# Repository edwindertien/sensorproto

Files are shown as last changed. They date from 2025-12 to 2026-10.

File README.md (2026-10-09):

# UniProto — sensor streaming for Arduino

UniProto is a tiny serial protocol, an Arduino library and a set of Python visualisers. Every
sensor or actuator in this repository — from a capacitive slider to a BLDC gimbal — speaks the
same few text commands, so a new setup is a short sketch plus a plotter, never a new protocol.
Built for the *Mastering Tinkering* and *Social Robot Design* courses at the University of Twente.

- **One protocol, many setups.** Enable a stream, set a rate, change a parameter: the same commands everywhere.
- **Firmware stays small.** A sketch registers *streams*, *parameters* and *actions*; the library does parsing, timing and formatting.
- **Readers are plain Python.** Each setup has a matplotlib (or browser) visualiser; anything that can read a serial port works too.
- **Any sketch is usable at once.** A generic web dashboard discovers a sketch's streams, parameters and actions by itself — [no plotter needed](#dashboard).

## Pick a setup

Click an icon to jump to its section.

<!-- GRID:START -->
<table>
<tr>
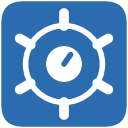
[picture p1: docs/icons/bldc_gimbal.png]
BLDC gimbal
<td align="center" valign="top" width="16%"><a href="#bldc-gimbal"><br><b>BLDC gimbal</b></a><br><sub>FOC haptic knob</sub></td>
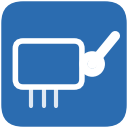
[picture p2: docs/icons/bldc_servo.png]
BLDC servo
<td align="center" valign="top" width="16%"><a href="#bldc-servo"><br><b>BLDC servo</b></a><br><sub>ESC, 50 Hz PWM</sub></td>
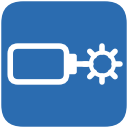
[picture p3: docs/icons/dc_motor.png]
DC motor
<td align="center" valign="top" width="16%"><a href="#dc-motor"><br><b>DC motor</b></a><br><sub>PID position / velocity</sub></td>
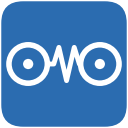
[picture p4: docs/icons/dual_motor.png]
Dual motor
<td align="center" valign="top" width="16%"><a href="#dual-motor"><br><b>Dual motor</b></a><br><sub>haptic master-slave</sub></td>
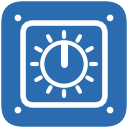
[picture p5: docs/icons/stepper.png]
Stepper
<td align="center" valign="top" width="16%"><a href="#stepper"><br><b>Stepper</b></a><br><sub>MKS SERVO42D</sub></td>
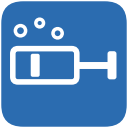
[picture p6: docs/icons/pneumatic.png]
Pneumatic
<td align="center" valign="top" width="16%"><a href="#pneumatic"><br><b>Pneumatic</b></a><br><sub>pump + pressure</sub></td>
</tr>
<tr>
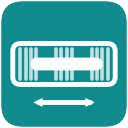
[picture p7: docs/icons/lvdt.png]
LVDT
<td align="center" valign="top" width="16%"><a href="#lvdt"><br><b>LVDT</b></a><br><sub>AC position sensor</sub></td>
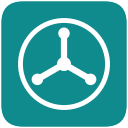
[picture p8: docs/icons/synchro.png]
Synchro
<td align="center" valign="top" width="16%"><a href="#synchro"><br><b>Synchro</b></a><br><sub>3-phase angle</sub></td>
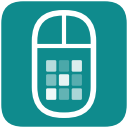
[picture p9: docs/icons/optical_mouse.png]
Optical mouse
<td align="center" valign="top" width="16%"><a href="#optical-mouse"><br><b>Optical mouse</b></a><br><sub>ADNS-2610 camera</sub></td>
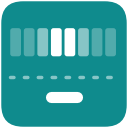
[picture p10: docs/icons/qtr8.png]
QTR-8
<td align="center" valign="top" width="16%"><a href="#qtr8"><br><b>QTR-8</b></a><br><sub>line / gray-code strip</sub></td>
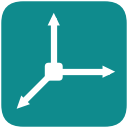
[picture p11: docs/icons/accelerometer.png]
Accelerometer
<td align="center" valign="top" width="16%"><a href="#accelerometer"><br><b>Accelerometer</b></a><br><sub>MMA7260, 3 axes</sub></td>
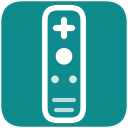
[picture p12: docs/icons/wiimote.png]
Wiimote IR
<td align="center" valign="top" width="16%"><a href="#wiimote"><br><b>Wiimote IR</b></a><br><sub>IR camera via I2C</sub></td>
</tr>
<tr>
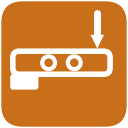
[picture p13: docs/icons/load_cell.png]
Load cell
<td align="center" valign="top" width="16%"><a href="#load-cell"><br><b>Load cell</b></a><br><sub>HX711 amplifier</sub></td>
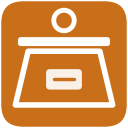
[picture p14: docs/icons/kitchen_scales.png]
Kitchen scales
<td align="center" valign="top" width="16%"><a href="#kitchen-scales"><br><b>Kitchen scales</b></a><br><sub>load cell + HX711</sub></td>
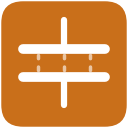
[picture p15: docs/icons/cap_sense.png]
Cap sense
<td align="center" valign="top" width="16%"><a href="#cap-sense"><br><b>Cap sense</b></a><br><sub>variable capacitor</sub></td>
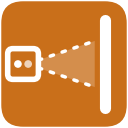
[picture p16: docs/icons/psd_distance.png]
IR distance
<td align="center" valign="top" width="16%"><a href="#psd-distance"><br><b>IR distance</b></a><br><sub>Sharp PSD</sub></td>
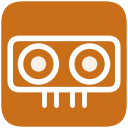
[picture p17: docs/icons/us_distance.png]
Ultrasonic
<td align="center" valign="top" width="16%"><a href="#us-distance"><br><b>Ultrasonic</b></a><br><sub>HC-SR04 scope view</sub></td>
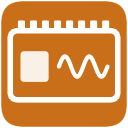
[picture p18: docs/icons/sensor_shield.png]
Sensor shield
<td align="center" valign="top" width="16%"><a href="#sensor-shield"><br><b>Sensor shield</b></a><br><sub>7 sensors, 1 board</sub></td>
</tr>
<tr>
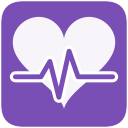
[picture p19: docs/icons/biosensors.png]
Biosensors
<td align="center" valign="top" width="16%"><a href="#biosensors"><br><b>Biosensors</b></a><br><sub>GSR + heart rate</sub></td>
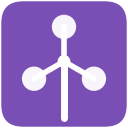
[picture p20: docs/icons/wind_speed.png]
Wind speed
<td align="center" valign="top" width="16%"><a href="#wind-speed"><br><b>Wind speed</b></a><br><sub>optical anemometer</sub></td>
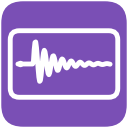
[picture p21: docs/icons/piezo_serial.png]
Piezo drums
<td align="center" valign="top" width="16%"><a href="#piezo-serial"><br><b>Piezo drums</b></a><br><sub>stream + heatmap</sub></td>
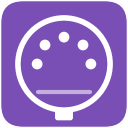
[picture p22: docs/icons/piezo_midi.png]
Piezo MIDI
<td align="center" valign="top" width="16%"><a href="#piezo-midi"><br><b>Piezo MIDI</b></a><br><sub>USB-MIDI drum kit</sub></td>
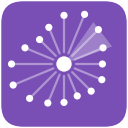
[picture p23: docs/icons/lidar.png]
Lidar
<td align="center" valign="top" width="16%"><a href="#lidar"><br><b>Lidar</b></a><br><sub>Hokuyo laser scanner</sub></td>
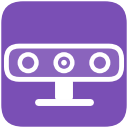
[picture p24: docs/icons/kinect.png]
Kinect
<td align="center" valign="top" width="16%"><a href="#kinect"><br><b>Kinect</b></a><br><sub>depth camera</sub></td>
</tr>
</table>

<sub>Rows: 🟦 Motion & actuation  ·  🟩 Position & angle  ·  🟧 Force, touch & distance  ·  🟪 Bio, sound & vision</sub>
<!-- GRID:END -->

**Prefer clicking?** Start the launcher — a small Flask app that opens in your browser, shows this
same grid, has a serial-port box with suggestions, and starts the matching reader when you click an icon:

```bash
python dashboard/launcher.py                 # opens http://127.0.0.1:5050
python dashboard/launcher.py --check         # which reader scripts / icons exist?
python dashboard/launcher.py --flask-port 5051 --no-browser     # other web port, don't open a tab
```

It needs only `flask` and `pyserial` (both in `dashboard/requirements.txt`) — no tkinter. It listens on
this computer only (`127.0.0.1`) and starts nothing that is not listed in `dashboard/setups.py`.
The launcher starts each reader as its own process (a normal plot window) with `--port <port in the box>`. Only one reader
can hold a serial port at a time, so a second one is refused until the first window is closed
(use the window's **×** button — see [the Leonardo note](#troubleshooting)). Setups that have
several readers (sensor shield, optical mouse, …) list all of them in the row under the grid.
Raw-probe readers marked *debug* stay hidden until you tick **Show debug readers**, and a click never starts one.
Every setup with a UniProto firmware also has a **Generic dashboard** button (see [below](#dashboard)); the setups that have no dedicated reader start it on click.
Only `piezo_midi` has neither — it is a MIDI device — and shows a hint instead.
The two PC-side apps, `kinect/app.py` and `hokuyo/app.py`, are started from their own folders without `--port`. They have no window to close, so they are listed under the grid with a **Stop** button; if an app prints a web address (e.g. Flask's `Running on http://127.0.0.1:…`), the launcher opens it and shows an *open* link.

## Quick start

```bash
# 1. firmware (PlatformIO) — one environment per setup; the sources are in src/<name>/
pio run -e dc_motor -t upload
pio device monitor -e dc_motor           # optional: talk to it by hand

# 2a. the dashboard and the launcher — need only flask + pyserial
pip install -r dashboard/requirements.txt
python dashboard/launcher.py                            # click a setup ...
python dashboard/dashboard.py --port /dev/tty.usbmodem21201    # ... or open the generic dashboard directly

# 2b. the per-setup plotters (matplotlib, numpy, …)
cd readers
python -m venv .venv && source .venv/bin/activate      # Windows: .venv\Scripts\activate
pip install -r requirements.txt                        # a superset: includes what the dashboard needs
python plot_dc_motor.py --port /dev/tty.usbmodem21201  # Windows: --port COM3
```

Details for macOS / Windows / Linux, finding your port and Linux permissions: [`readers/SETUP.md`](readers/SETUP.md).
`readers/requirements.txt` is a superset of `dashboard/requirements.txt`, so one virtual environment can run everything.

## The generic dashboard — any sketch, no plotter needed

`dashboard/dashboard.py` is one web page that works with **any** UniProto sketch. It asks the board what it has
(`?`), then lets you chart a stream live, change parameters, press actions and record to CSV — so a new setup is
usable the moment its firmware runs, before anyone has written a plotter.

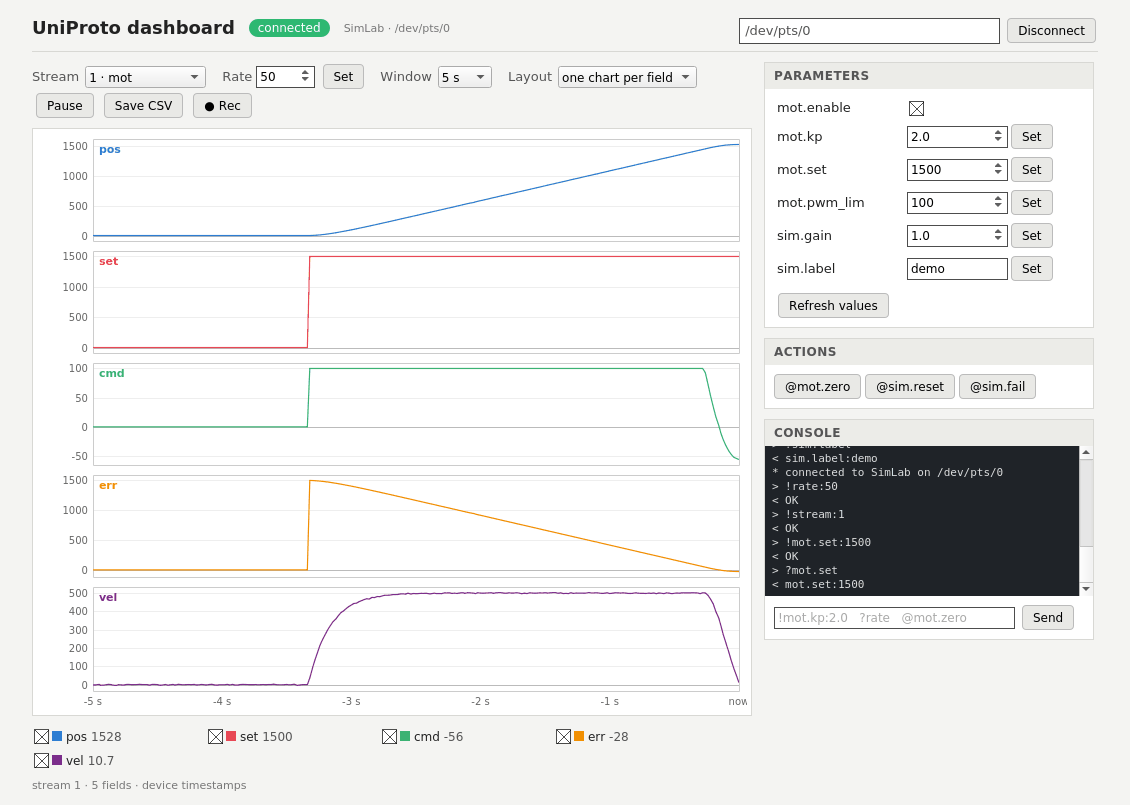
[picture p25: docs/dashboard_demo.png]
The generic dashboard showing a simulated servo: a setpoint step sent from the Parameters panel


```bash
python dashboard/dashboard.py --port /dev/tty.usbmodem21201       # then open http://127.0.0.1:5000
python dashboard/dashboard.py --port COM3 --stream 1 --rate 50    # ...and start streaming stream 1 at 50 Hz
python dashboard/uniproto_sim.py                                     # no hardware? a simulated board (macOS / Linux)
```

It also starts from the launcher: every setup has a **Generic dashboard** button, and the setups without a dedicated reader start it on click.

- **Streams.** Pick one from the list. It is **one at a time**, because CSV lines carry no stream id — two enabled streams of
  different widths could not be told apart. The page switches streams for you, and a switch takes effect at the board's own `OK`,
  so nothing from the old stream leaks into the new chart.
- **Charts.** *Over time:* one chart per field or all in one, a 2–60 s window, pause, and a legend with live values and tick boxes.
  Drawing is peak-preserving, so a single-sample spike (a piezo hit) is never lost.
  *Latest row:* plots the newest record against the field index, with faint ghosts of the previous rows — the right view for a sensor
  array (QTR-8: one value per sensor) or a capture frame (LVDT / synchro: 50+ samples). Streams of more than 12 fields open in it by default;
  **skip first** hides header fields such as `id, off, cnt`. Bookmark a view with `?layout=one&window=5` or `?view=row&skip=3`.
- **Parameters** become inputs — the current values are read back from the board, on/off values get a checkbox, and a field
  you have edited is not overwritten by the refresh. **Actions** become buttons, and a console with a command box works like a serial monitor.
- **Recording.** **Rec** streams every row to `recordings/<device>_<stream>_<time>.csv` (add `recordings/` to `.gitignore`);
  **Save CSV** downloads what is in the buffer. Times are the board's own (`!timestamp:1`), in seconds.
- **Field names** come from the stream's `units` string when it has exactly one unique name per field (`"pos,set,cmd,err,vel"`);
  otherwise the fields are called `f0, f1, …`. A field called `sid` (an explicit stream-id column) starts hidden.
- **Robust to the usual trouble.** It opens the port the Leonardo-safe way (DTR low → high, dropped again on close), retries while a board is still booting,
  says clearly when the port is busy or the board does not answer `?` (wrong baud? — use `--baud`; the LVDT runs at 38400), and notices when the board is unplugged.
  A page left open survives a restart of the server.

**Limits of this prototype.** CSV only — binary streams such as the ADNS image cannot be shown. A frame sent in several chunks (the LVDT's 480 samples
in chunks of 60) shows one chunk at a time, not the assembled frame. It listens on this computer only;
anyone who can reach it can drive the connected hardware, so do not expose it to a network.

---

# How the stream library works

```
 Arduino sketch                              host (Python, serial monitor, …)
 ┌──────────────────────┐   text commands   ┌──────────────────────────┐
 │ UniProto             │ ◄──────────────── │  !stream:+1   !rate:50   │
 │  streams  (periodic) │                   │  !kp:2.0      @zero      │
 │  params   (get / set)│ ────────────────► │  1,684,672,684,30        │
 │  actions  (one-shot) │   data lines      │  (one line per tick)     │
 └──────────────────────┘                   └──────────────────────────┘
```

A sketch registers three kinds of things, all by name:

| Kind | What it is | Example |
|---|---|---|
| **stream** | a record emitted every tick while enabled | `pos, set, cmd, err, vel` of a motor |
| **param** | a value the host can read (`?key`) or write (`!key:value`) | `mot.kp`, `qtr.thr` |
| **action** | a one-shot command (`@name`) | `@mot.zero` |

## Commands

One command per line (newline terminated). Replies are `OK`, `key:value`, or `ERR <reason>`.

| Command | Meaning |
|---|---|
| `?` | capabilities as one JSON line: device name, every stream (`id`, `name`, `schema`, `units`), params, actions |
| `?rate` `?format` `?timestamp` `?stream` | read a core setting (`rate:50`; `stream:` lists the enabled ids, `0` if none) |
| `?key` | read a parameter → `key:value` |
| `!rate:N` | emit rate in Hz, clamped to 1–500. *Every enabled stream is emitted once per tick.* |
| `!format:csv` `txt` `ap` `bin` | output format (below) |
| `!timestamp:0\|1` | prefix each record with the time since boot |
| `!stream:N` | enable **only** stream N · `!stream:+N` add · `!stream:-N` remove · `!stream:0` all off |
| `!key:value` | set a parameter |
| `@action[:args]` | run an action |

Errors you may see: `ERR no-such-param`, `ERR set-failed`, `ERR get-failed`, `ERR set-missing-colon`,
`ERR bad-format`, `ERR no-such-action`, `ERR unknown-cmd`. Lines may be at most 63 characters on AVR boards (`UNIPROTO_CMD_BUF`): a longer line overflows the buffer,
the front is discarded and the tail is parsed as a separate — usually bogus — command. `\r` is ignored, so CRLF is fine.

## Output formats

| `!format:` | Looks like | For |
|---|---|-----|
| `csv` (default) | `684,672,684,30` — values only, comma separated, one line per stream per tick | Python readers |
| `ap` | `raw:684,pos:12` — `key:value` pairs | Arduino Serial Plotter |
| `txt` | human-readable debug text | typing by hand |
| `bin` | binary frames (below) | image / block data |

**CSV carries no stream id.** With `!timestamp:1` each line starts with the time since boot in
**seconds** (3 decimals). If a reader has to tell two streams apart, see the design rules below.

### Binary frame (`!format:bin`)

```
AA 55 | stream id (u8) | flags (u8) | payload length (u16, little-endian) | [timestamp u32 ms, if flags & 1] | payload
```

Fields inside the payload are raw little-endian `u16` / `i32` / `float32` in the order the sketch
writes them. The sketch must pass the exact payload length to `begin(sid, len)`; fields that would
overflow it are silently dropped. `bytes()` (blocks, e.g. camera pixels) only exists in binary mode —
in CSV it is ignored. The optical-mouse reader ([`plot_adns_picture.py`](readers/plot_adns_picture.py)) is a complete example.

## Design rules we converged on

These came out of debugging real setups (the long version is in [`docs/context.md`](docs/context.md)):

1. **One stream = one record type, and never enable two same-width streams the reader can't tell apart.**
   Interleaved streams of equal field count get swapped the moment a line is dropped. Either put everything
   in one wide stream (piezo: `A0..A3,dA0..dA3`) or start every record with an explicit id (sensor shield).
2. **Stream raw values, derive in Python.** The QTR-8 sends 8 raw decay times; binary, gray code and line
   position are computed in the reader. Pre-computed streams exist for consumers without a PC.
3. **Slow sensors never block the emit callback.** Poll them in `loop()` into cached variables; the callback only copies.
4. **Namespace parameters** by device: `foc.k`, `mot.kp`, `qtr.thr`, `us.rate`.
5. **Readers parse first, filter later.** Try `float()` on every field and skip the line on `ValueError`;
   banners, `OK` and `ERR` lines then fall out naturally.
6. **Name your fields.** Put one unique name per field in the stream's `units` string (`"pos,set,cmd,err,vel"`) —
   the dashboard labels its charts with it.

## Writing a sketch

```cpp
#include <Arduino.h>
#include "UniProto.h"

UniProto proto(Serial, "MySensor");

static void emitRaw(UniProto&, uint8_t sid, UniFrameWriter& w, void*) {
    w.begin(sid);                      // for bin: w.begin(sid, payloadBytes)
    w.u16(analogRead(A0), "raw");      // keys are only used by ap / txt
    w.f32(millis() / 1000.0f, "t", 3); // value, key, decimals
    w.end();
}

static bool getParam(UniProto&, const char* k, char* out, size_t n, void*) {
    if (!strcmp(k, "my.gain")) { snprintf(out, n, "%.2f", (double)gain); return true; }
    return false;
}
static bool setParam(UniProto&, const char* k, const char* v, void*) {
    if (!strcmp(k, "my.gain")) { gain = UniProto::parseFloat(v); return true; }
    return false;
}
static bool doZero(UniProto&, const char*, const char*, Stream& out, void*) {
    zero(); out.println(F("zeroed")); return true;
}

void setup() {
    Serial.begin(115200);
    proto.begin();
    proto.setRateHz(50);
    proto.registerStream({1, "raw", "u16,f32", "adc,s", emitRaw, nullptr});
    proto.registerParam ({"my.gain", UniProto::ParamType::FLOAT, getParam, setParam, nullptr});
    proto.registerAction({"my.zero", doZero, nullptr});
}
void loop() { proto.tick(); }
```

Then add a `[env:mysetup]` block (copy any existing one) and `src/mysetup/main.cpp`.

**Gotchas**

- The writer has `u16`, `i32`, `f32` and `bytes` — **no `u32`**. Microsecond timestamps fit `i32` for ~35 minutes; send them relative to session start.
- The `schema` string is only printed by `?`. The dashboard uses `units` as the field names when it holds exactly one unique name per field (design rule 6); nothing else parses either.
- Limits are compile-time: `UNIPROTO_MAX_STREAMS` (default 8), `UNIPROTO_MAX_PARAMS` (16), `UNIPROTO_MAX_ACTIONS` (8) — raised per environment with `build_flags` in `platformio.ini`.
  Streams are enabled through a 16-bit mask over registration order, so at most 16 streams per sketch.
- A blocking sensor read (ultrasonic `pulseIn`, capacitive sensing) delays the whole tick — see rule 3.

## Writing a reader

You often do not need to: the [generic dashboard](#dashboard) already charts any sketch. Write a dedicated reader when a setup needs
a special view — an oscilloscope, an image, an XY plot, a sound.

```python
import serial, time
ser = serial.Serial(PORT, 115200, timeout=0)
time.sleep(2)                                  # Uno / Duemilanove reset when the port opens
for cmd in ("!format:csv", "!timestamp:0", "!rate:50", "!stream:+1"):
    ser.write((cmd + "\n").encode()); time.sleep(0.15)
ser.reset_input_buffer()

buf = b""
while True:
    buf += ser.read(ser.in_waiting or 1)
    while b"\n" in buf:
        line, buf = buf.split(b"\n", 1)
        try:
            vals = [float(v) for v in line.decode().split(",")]
        except ValueError:
            continue                           # OK / ERR / banner lines
        print(vals)
```

For plotters: call `plt.pause(0.005)` **unconditionally** at the bottom of the loop (inside an `else` it starves the GUI),
keep the `Button` objects in a list (otherwise they are garbage-collected and stop responding), and use
`x.max() - x.min()` instead of `x.ptp()` (removed in NumPy 2). Add `import uniproto_backend  # noqa` before
`matplotlib.pyplot` to get the right backend on every OS.

## Project layout

```
platformio.ini            one [env] per setup (board, libraries, build flags);  src_dir = src
src/<setup>/main.cpp      the firmware: wiring + registerWith() calls   (one folder per setup)
lib/uniproto/             UniProto + UniWriter                          (the library)
lib/modules/              mod_*.h/.cpp — reusable hardware drivers (motors, ADNS-2610, HX711, …)
dashboard/                the web side — launcher, generic dashboard, simulator
  setups.py               the list of setups: names, readers, groups   ← launcher, icons and README grid read this
  launcher.py             click-to-start launcher (Flask, opens in the browser)
  dashboard.py            generic web dashboard for ANY UniProto sketch (Flask)
  uniproto_sim.py         a simulated UniProto board on a pseudo-terminal (macOS / Linux), for the dashboard
  requirements.txt        flask + pyserial: all the dashboard needs
readers/                  the per-setup plotters (matplotlib; one or more per setup)
  plot_*.py               (the *_debug ones are raw probes)
  plot_adc_blocks.py      generic viewer for binary ADC-block streams (not tied to one setup)
  sensorhost/             browser host (Web Serial, Chrome/Edge): open index.html
  example.py              template for a new reader
  uniproto_backend.py     picks the matplotlib backend per OS
  requirements.txt  SETUP.md
kinect/app.py  hokuyo/app.py     the two PC-side apps (no Arduino); started by the launcher
tools/
  make_icons.py           draws docs/icons/*.png from dashboard/setups.py
  update_readme_grid.py   rebuilds the grid above; --check reports README drift
docs/
  icons/                  128 px tiles (README) and sm/ 96 px tiles (launcher)
  context.md              technical decisions and debugging log
  bldc_gimbal.md          BLDC gimbal manual
recordings/               CSV files written by the dashboard's Rec button (keep out of git)
```

**Adding a setup:** write `src/<name>/main.cpp` and an `[env:<name>]` block in `platformio.ini`; add a `Setup(...)` entry to `dashboard/setups.py`, a glyph to `tools/make_icons.py`, and an
`` section below; then run `python tools/make_icons.py` and `python tools/update_readme_grid.py`
(`--check` tells you what is missing). To use a photo instead of a drawn icon, drop a PNG with the same file name into `docs/icons/` and `docs/icons/sm/`.

---

# Setups

Status: ✅ documented · 🚧 stub (hardware listed, details to follow). bldc_servo, stepper, pneumatic and wiimote have no dedicated reader yet and use the [generic dashboard](#dashboard); piezo_midi is a MIDI device and needs none.

## BLDC gimbal — `bldc_gimbal` ✅

Field-oriented control of a gimbal motor as a programmable haptic knob: spring, detents, damper, or a sweep.
**Hardware:** DRV8313 LittleFOC driver · AS5600 magnetic encoder · BDUA 2204 motor (7 pole pairs) · Uno.
**Firmware:** `src/bldc_gimbal/` — a minimal FOC written for this repo (SimpleFOC does not fit the Uno's 32 KB). All three phases run at 62.5 kHz.
**Wiring:** pins 9, 10, 11 → DRV8313 IN1–IN3 · pin 8 → EN · A4/A5 → AS5600 SDA/SCL.
**Reader:** `plot_bldc_gimbal.py` · full manual: [`docs/bldc_gimbal.md`](docs/bldc_gimbal.md)

| Param | Default | Meaning |
|---|---|---|
| `foc.enable` | 0 | 1 = drive the motor |
| `foc.mode` | 1 | 0 open loop · 1 spring · 2 detents · 3 damper · 4 spring + damper · 5 sweep |
| `foc.k` | 2.0 | spring stiffness (V/rad) |
| `foc.b` | 0.3 | damping |
| `foc.vlimit` | 2.0 | maximum torque voltage — **start low** |
| `foc.poles` | 7 | motor pole pairs |
| `foc.sweep_hz` | 0.5 | sweep rate, positive = clockwise |
| `@foc.zero` | | zero the position here |

Bring-up: `!stream:1` → `!rate:20` → `!foc.enable:1` → `!foc.mode:5` → `!foc.sweep_hz:0.5`. Check that clockwise and counter-clockwise sweeps feel the same, then switch to spring mode.
If the spring pushes instead of pulls, swap two motor phase wires.

## BLDC servo — `bldc_servo` 🚧

BLDC motor on a standard ESC, driven with 50 Hz servo PWM, no position feedback. Board: Uno. Firmware: `src/bldc_servo/`. **Reader:** the [generic dashboard](#dashboard).

## DC motor — `dc_motor` ✅

A 12 V geared DC motor under position, velocity or direct-PWM control, with a potentiometer as setpoint.
**Hardware:** 12 V DC motor · 1:30 gearbox · US-Digital 100 PPR quadrature encoder on the rear shaft · Arduino Motor Shield (L298P) · Uno.
**Wiring:** motor on shield **channel B** — PWM pin 11 (Timer 2, ~31 kHz), DIR pin 13, BRAKE pin 8 · encoder A → pin 2, B → pin 3 (both interrupts) ·
setpoint pot on **A3 = GND, A4 = signal, A5 = VCC**. *Do not use A0/A1: the shield uses them for current sense.*
**Counts:** 100 PPR × 4 × 30 = **12 000 counts per output revolution**.
**Stream 1 `mot`:** `pos, set, cmd, err, vel, mA` (motor current from A1, 2.96 mA per ADC count).
**Reader:** `plot_dc_motor.py` — position / velocity / PWM+error / current charts and a control panel.

| Param | Default | Meaning |
|---|---|---|
| `mot.enable` | 1 | controller on (starts enabled) |
| `mot.mode` | 1 | 0 direct PWM · 1 position PID · 2 velocity PID |
| `mot.kp` `mot.ki` `mot.kd` | 2.0 · 0 · 0 | PID gains (velocity mode needs very different values than position mode) |
| `mot.pwm_lim` | 100 | PWM ceiling, 0–255 — raise gradually |
| `mot.set` | | setpoint in ticks (pos) or counts/s (vel); the pot overwrites it every 50 ms |
| `mot.pot_scale` | 12000 | full pot travel in ticks (position mode) |
| `mot.vel_scale` | 20000 | full pot travel in counts/s (velocity mode) |
| `mot.vel_alpha` | 0.5 | velocity filter, 1 = off, smaller = smoother (velocity is measured over 20 ms windows) |
| `mot.ctrl_hz` | 500 | control-loop rate — `!mot.ctrl_hz:50` shows students what a 10× slower loop does |
| `@mot.zero` `@mot.brake` `@mot.coast` | | zero the encoder · engage / release the brake |

## Dual motor (haptic) — `haptic` ✅

Two coupled motors for master–slave haptics: move one and the other follows (and pushes back).
**Hardware:** two Maxon motors with encoders · L293 driver · Uno. **Env:** `haptic` (firmware `src/haptic/`, driver `mod_motors`).
**Stream 3:** `pos0, pos1, set0, set1, cmd0, cmd1, err0, err1`.
**Commands:** `!stream:3`, `!motor0.enable:1`, `!motor0.kp:1.5`, `!motor0.set:500`, `!motor0.pwm:100`, `!motor0.pwm_lim:180`, `!motor.link:3` (bidirectional coupling), `!motor.link_scale:0.5`, `@motor.zero`, `@motor.stop`.
**Readers:** `plot_haptic_dual_motor.py` — strip charts plus a command panel with presets ·
`plot_dual_motor.py` — the same monitor with a scrolling window of 100–2000 samples drawn from a larger circular history (`--history`), **rec** (live CSV log) and **save buffer** (dump the history to CSV) ·
`plot_haptic_dual_motor_stream.py`, `plot_haptic_dual_motor_stream_vel.py` (adds a velocity estimate) ·
`plot_haptic_dual_motor_debug.py` (*debug*: raw probe that shows what the Arduino sends).

## Stepper — `stepper` 🚧

MKS SERVO42D closed-loop stepper controller driven with step/dir signals. Board: Uno. Firmware: `src/stepper/`. **Reader:** the [generic dashboard](#dashboard).

## Pneumatic — `pneumatic` 🚧

Pump and valve with a Honeywell pressure sensor read through an HX711. Board: Uno. Firmware: `src/pneumatic/`. **Reader:** the [generic dashboard](#dashboard).

## LVDT — `lvdt` 🚧 *(waveform view still being verified)*

Linear variable differential transformer: a core sliding through a primary coil changes how the two secondary coils balance.
**Wiring:** pins 9 and 10 output a filtered-PWM sine in **anti-phase** (≈100 Hz) and drive the primary · the two secondaries, in series opposition, go to **GND and A1** (optional series capacitor).
**Baud:** 38 400 (the 5 kHz timer interrupt is timing critical).
**Streams:** 1 `lvdt.pos` — position −1…+1 from correlating the received signal with the excitation (amplitude = distance from centre, phase = side) ·
2 `lvdt.frame` — the raw capture: `id, off, cnt, s0…s(cnt-1)` per line (480 samples = 10 cycles, in chunks).
**Param / action:** `lvdt.scale` · `@lvdt.zero`. **Reader:** `plot_lvdt.py` — full-frame oscilloscope, single-cycle zoom, position chart and bar.

## Synchro — `synchro` 🚧 *(known issue)*

Three-phase synchro transformer: the rotor angle is recovered from a filtered-PWM sine sent on three phases.
**Wiring:** phases on pins 9 (0°), 5 (120°) and 10 (240°) · receiver on **A1**. Timer 2 interrupt at 5 kHz, 48-sample sine table, frames of 480 samples (10 cycles) sent in chunks of 60. **Baud 115 200** (the reader's default).
Angle comes from cross-correlation. **Known issue:** the angle is still erratic because the ISR's capture array can be read while it is being written; double-buffering is planned.
**Reader:** `plot_synchro.py`.

## Optical mouse — `optical_mouse` ✅

An ADNS-2610 optical-mouse sensor read over its bit-banged serial interface (A4/A5): relative motion, or a 18×18 pixel image of the surface.
**Board:** Uno · module `mod_adns2610`.
**Streams:** 6 `adns.motion` — `dx, dy` · 7 `adns.frame` — the image, in chunks of `id, w, h, off, n` + `n` six-bit pixels (binary format).
**Params:** `adns.led` (illumination), `adns.capture` (`1` grabs one frame), `adns.motion_on` (`0` frees bandwidth during an image read), `adns.resync`; read-only diagnostics `adns.dx dy squal maxpix minpix pixsum shutter status`, and `adns.w adns.h adns.chunk_px`.
**Readers:** `plot_adns_picture.py` (image; pass `--continuous` to keep refreshing, `--flip_x` / `--flip_y` to mirror) · `plot_adns_motion.py` (dx/dy trace) · `plot_adns_debug.py` (*debug*: raw probe).

## QTR-8 reflectance array — `qtr8` ✅

Eight infrared reflectance sensors (Pololu QTR-8RC) under a vehicle, or over a strip: line following, or a gray-code position encoder.
**Board:** Arduino Duemilanove, ATmega328P (`diecimilaatmega328`). **Wiring:** sensors on digital pins **4–11**, 5 V.
All eight are read in parallel by timing how long each RC node takes to discharge: short = white, long = black (timeout 2500 µs = full black).

| Stream | Content | For |
|---|---|-----|
| 1 `raw` | 8 decay times in µs | everything — the Python reader derives the rest |
| 2 `bin` | 8 × thresholded 0/1 | use without Python |
| 3 `line` | line position 0–255 | line follower without Python |
| 4 `gray` | gray-code pattern 0–255 | position strip without Python |

**Params:** `qtr.thr` (binary threshold, µs, default 1000), `qtr.timeout` (default 2500). **Action:** `@qtr.cal` (threshold from 50 samples).
**Reader:** `plot_qtr8.py` — heat-map squares, binary squares with their binary and gray-code value, raw decay charts with the threshold, and a bottom chart (tick boxes) with binary value, gray code and line position, all 0–255.
**Line position** is a pure weighted centroid, `Σ(i·raw[i]) / Σ raw[i]`, scaled to 0–255 — no threshold, so it moves smoothly as the line crosses between sensors.
**Gray code:** `gray = bin ^ (bin >> 1)` — one bit changes per step, which is what you want on a 256-position paper strip.

## Accelerometer — `accelerometer` ✅

MMA7260 three-axis analog accelerometer. **Wiring:** X = A0, Y = A1, Z = A2 · SLEEP = pin 2 (high = active) · GS1 = pin 3, GS2 = pin 4 select the range (both low = ±1.5 g, the default; GS1 high = ±2 g; GS2 high = ±4 g; both high = ±6 g). Board: Uno. **Reader:** `plot_accelerometer.py`.

## Wiimote IR camera — `wiimote` 🚧

The Wiimote's infrared camera on I²C at 400 kHz. Board: Uno. Compiles; the camera initialisation sequence still needs verifying on hardware. **Reader:** the [generic dashboard](#dashboard).

## Load cell — `load_cell` ✅

Single HX711 amplifier, channel A, gain 128. **Wiring:** DOUT = A3, SCK = A2. Board: Uno. **Reader:** `plot_load_cell.py`.
**Calibration:** 1. flash and open the reader · 2. remove all weight, click **zero** (tare) · 3. place a known weight · 4. enter it, click **calc scale** · 5. click **verify**.

## Kitchen scales — `kitchen_scales` ✅

The same HX711 module as the load cell, wired differently (DOUT = A1, SCK = A0) and calibrated for 0–5000 g. Board: Uno.
**Readers:** `plot_kitchen_scales.py`; calibrate with `plot_load_cell.py` using the procedure above.

## Capacitance sensing — `cap_sense` ✅

A variable capacitor (~200 pF) measured through a 10 MΩ resistor. **Wiring:** SEND = A3 (charges through the resistor), SENSE = A0.
**Board:** Arduino Duemilanove with ATmega168 — only 14 KB flash, so keep this sketch lean.
**Modes (`!cap.mode`):** 0 = analog voltage after a fixed charge delay (best for small C, default) · 1 = count-to-threshold (better for larger C). `!cap.delay:200` sets the charge delay in µs for mode 0.
**Reader:** `plot_cap_sense.py`.

## IR distance (Sharp PSD) — `psd_distance` 🚧

Sharp GP2Y0A710 analog infrared distance sensor via `mod_psd`. Board: Uno. Reader: `plot_psd_distance.py`.

## Ultrasonic distance — `us_distance` ✅

An HC-SR04 shown as an **oscilloscope**: see the 10 µs trigger pulse, the echo pulse that follows, and how the gap between them shrinks as an object approaches — or vanishes on a time-out.
**Wiring:** TRIG = pin 3, ECHO = pin 2 (interrupt). **Board:** Uno.
**Streams:** 1 `pulse` — `trig_us, echo_us, echo_dur, cm` (timestamps in µs since session start; `echo_dur` 0 and `cm` −1 mean time-out) · 2 `dist` — `cm` only.
**Params:** `us.rate` (1–20 Hz, default 10), `us.timeout` (µs, default 30 000 ≈ 5 m).
**Reader:** `plot_us_distance.py` — trigger and echo traces with a **timebase** from 100 µs to 500 ms (zoom in to see the acoustic gap, out to see the pulse train), a distance chart and a large readout.

## Sensor shield — `sensor_shield` ✅

One board, seven sensors, seven streams — a tour of the typical analog and digital sensor interfaces.
**Power:** the shield runs at **3.3 V** while the Uno's ADC reference is 5 V, so shield signals span 0–675 counts and the Hall mid-point is 338 (`ADC_MID`, `ADC_SHIELD_FS` at the top of `main.cpp` — change them if you power it at 5 V).
**Library:** CapacitiveSensor (installed by PlatformIO).

| Pin | Sensor | Notes |
|-----|---|---|
| A0 | potentiometer | also the RC-ADC reference |
| A1 | external input J1 | switchable AC/DC |
| A2 | foil pressure sensor | 100 k pull-up, inverse calibration |
| A3 | strain gauge | via INA122 amplifier, 500 g full scale |
| A4, A5 | Hall sensors | two phases → rotation angle (9 magnets, 270°) |
| D2, D3 | quadrature encoder | 5 kHz timer interrupt |
| D4 | RC-ADC | 100 k + 100 nF to A0, charge and discharge timed |
| D6, D7, D11 | capacitive slider | |
| D8, D12 | HC-SR04 | trigger, echo — range ~10 m |

**Streams** (each record starts with its own id so the reader can tell them apart): 1 analog A0–A5 · 2 foil, strain · 3 hall angle · 4 encoder · 5 capacitive slider · 6 RC-ADC · 7 ultrasonic.
**Readers:** `plot_sensor_shield.py` (everything on one page) · `plot_sensor_shield_flask.py` (same, in the browser at `http://localhost:5000`) · `plot_sensor_shield_weight.py` (foil vs strain as an XY hysteresis plot) · `plot_sensor_shield_angle.py` (potentiometer vs Hall angle — a straight line if both sit on one shaft). In the XY plots press **`c`** to clear the trail.

## Biosensors — `biosensors` ✅

Grove GSR (skin conductance, **A0**) and an ear-clip heart-rate sensor (**A5**). Board: Uno. **Reader:** `plot_biosensors.py`.
GSR is a slow signal — use **auto-fit** after attaching the electrodes. BPM is the average over the last 8 beats.

## Wind speed — `wind_speed` ✅

An optical-gate anemometer: an IR LED (A2/A3) and photodiode (A0/A1) count fan blades. Board: Uno.
**Params:** `wind.thr` (pulse threshold, default 512), `wind.blades` (default 3), `wind.circ` (fan circumference in m, default 0.05).
**Readers:** `plot_wind_speed.py` (**auto (midpoint)** sets the threshold from the live signal).

## Piezo drums (serial) — `piezo_serial` ✅

Four piezo plates on **A0–A3** as drum pads, streamed for visualisation. **Board: Arduino Leonardo.**
**Stream 1:** `A0, A1, A2, A3, dA0, dA1, dA2, dA3` — raw ADC plus an IIR-smoothed **derivative** (`d = (1-s)·d + s·(raw - prev)`, `s` = `piezo.smooth`, default 0.7).
Trigger on the derivative, not the raw value: it ignores baseline drift, crosstalk and slow voltage build-up.
**Reader:** `plot_piezo_serial.py` — raw charts, derivative charts with the threshold, and four impact circles that glow with hit strength; each pad plays a synthesised kick, snare or hi-hat (pygame, no sound files; `--nosound` to disable). Buttons adjust the threshold and smoothing.
Drum map: A0 kick · A1 snare · A2 closed hi-hat · A3 open hi-hat.

## Piezo MIDI — `piezo_midi` ✅

The same four pads, but the Leonardo appears as a **USB-MIDI device**: a hit sends a note-on (velocity from the peak) on channel 10. No reader — open a Drum Rack in Ableton or any GM drum synth.

| Pad | Note | Drum |
|-----|---|---|
| A0 | 36 | kick |
| A1 | 38 | snare |
| A2 | 42 | closed hi-hat |
| A3 | 46 | open hi-hat |

Remap by editing `NOTES[]` in `src/piezo_midi/main.cpp`. Library: MIDIUSB. Tune `THRESHOLD`, `PEAK_WINDOW` and `RETRIGGER` at the top of the sketch; use `piezo_serial` first to see what your pads actually deliver.

## Lidar (Hokuyo) — `lidar` 🚧

Hokuyo 2D laser scanner. Python only (no Arduino firmware). **App:** `hokuyo/app.py`, started by the launcher from the `hokuyo/` folder.

## Kinect — `kinect` 🚧

Depth camera. Python only (no Arduino firmware). **App:** `kinect/app.py`, started by the launcher from the `kinect/` folder.

---

# Troubleshooting

- **No data / `Port busy`.** Only one program can open a serial port. Close the Arduino IDE's serial monitor, the PlatformIO monitor and any other reader first.
- **Leonardo / piezo reader hangs after the first run.** The Leonardo sketch waits (`while(!Serial)`) for DTR to rise. On macOS the OS can leave DTR high after a program ends, so the next run sees no edge. `plot_piezo_serial.py` opens the port with DTR low → high and drops DTR again on close — which happens reliably only when you close the window with its **×** button — Ctrl-C can interrupt before DTR is dropped. Always close with ×.
- **macOS shows two ports per board** (`/dev/tty.usb…` and `/dev/cu.usb…`). The readers were developed with `tty.`; the launcher lists those first.
- **Launcher: "Address already in use".** Another program has web port 5050 — start it with `--flask-port 5051`. (5000 is avoided on purpose: macOS uses it for AirPlay.)
- **The Kinect / Hokuyo app dies at once with `ModuleNotFoundError`.** The launcher runs apps with *its own* Python. If an app needs packages that live in another environment, point that reader at it in `dashboard/setups.py`: `R("kinect/app.py", "Kinect app", port=False, server=True, python="../kinect/.venv/bin/python")`.
- **Dashboard: the page will not open, or answers "403 Forbidden / AirTunes" (macOS).** Open `http://127.0.0.1:5000` — not `localhost` — because macOS AirPlay Receiver can answer on port 5000 for `localhost`; or switch AirPlay Receiver off in System Settings, or use `--flask-port 5001`. Browsers also refuse some ports outright (5060 and 5061 among them), so avoid those.
- **Dashboard: "the board did not answer '?'".** Wrong baud (`--baud`), a board that is not running a UniProto sketch, or a board still booting (it retries four times). **"could not open … busy"** means another program has the port — close other readers and serial monitors.
- **A reader says "not found" in the launcher.** Run `python dashboard/launcher.py --check`, then fix the script name in `dashboard/setups.py`.
- **A reader dies immediately from the launcher.** The status line shows the last line of its error; the complete output is in `<temp dir>/uniproto_launcher/<script>.log`.
- **Plots lag or freeze on a slow machine.** Lower `!rate:`, and for the dual-motor reader watch the `draw` and `rx` numbers in its status line: rising `draw` means plotting is the bottleneck, rising `rx` means the serial data is not being consumed fast enough.

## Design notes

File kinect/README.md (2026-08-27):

# Kinect for Xbox 360 live visualiser

Standalone Flask dashboard showing the Kinect v1's RGB and depth streams
side by side. Not wired into the UniProto Arduino stream — this talks
straight to the Kinect over its own USB connection via libfreenect.

## 1. Try it without hardware

```
python3 -m venv venv
source venv/bin/activate
pip install -r requirements.txt
python app.py --simulate
```

Open http://127.0.0.1:5002 — synthetic RGB and depth frames let you check
the layout before touching libfreenect or the sensor.

## 2. Build libfreenect + its Python bindings (macOS)

Homebrew's `libfreenect` bottle doesn't include the Python module (a past
PR to add it was rejected upstream over a linking issue), so it needs a
manual build. This recipe is the one actually verified working end to
end on macOS (Apple Silicon, AppleClang 17, Python 3.11 via venv) — a
plain `cmake .. -DBUILD_PYTHON3=ON` is not enough; each piece below
addresses a specific failure hit along the way.

**One source change is required first.** libfreenect's own
`wrappers/python/CMakeLists.txt` links the extension module directly
against `Python3_LIBRARIES`. On this toolchain that resolves to the
*static* `libpython3.11.a`, which pulls a whole second copy of CPython's
built-in modules (`_ssl`, `posix`, `gc`, ...) into `freenect.so` —
two interpreters colliding in one process, which crashes on import with
a segfault. Open `wrappers/python/CMakeLists.txt`, find (around line 66):

```
target_link_libraries(cython${Python_BUILD_VERSION}_freenect
  freenect_sync
  ${Python${Python_BUILD_VERSION}_LIBRARIES})
```

and delete the `${Python${Python_BUILD_VERSION}_LIBRARIES}` line, so it
reads just:

```
target_link_libraries(cython${Python_BUILD_VERSION}_freenect
  freenect_sync)
```

Then, with the venv for this project active (`source venv/bin/activate`,
so `numpy` is already installed and CMake targets the right Python):

```
brew install libusb cmake pkg-config
pip install cython setuptools   # setuptools restores distutils, removed in Python 3.12+

git clone https://github.com/OpenKinect/libfreenect
cd libfreenect
# apply the CMakeLists.txt edit above before configuring

rm -rf build
mkdir build && cd build

cmake .. \
  -DBUILD_PYTHON3=ON \
  -DBUILD_CPP=OFF \
  -DPython3_EXECUTABLE=$(which python3) \
  -DCMAKE_MODULE_LINKER_FLAGS="-undefined dynamic_lookup -Wl,-no_fixup_chains" \
  -DCMAKE_INSTALL_PREFIX="$VIRTUAL_ENV" \
  -DCMAKE_INSTALL_RPATH="$VIRTUAL_ENV/lib" \
  -DCMAKE_BUILD_WITH_INSTALL_RPATH=ON

make
make install
```

What each non-default flag is for, in case a future rebuild only hits
some of these:

| Flag | Fixes |
|---|---|
| `-DBUILD_CPP=OFF` | Skips libfreenect's C++ demo viewer, unrelated to Python bindings and broken by a separate stale-CommandLineTools issue on this machine |
| `-DPython3_EXECUTABLE=$(which python3)` | Forces CMake to target the venv's Python, not Homebrew's system default |
| `-DCMAKE_MODULE_LINKER_FLAGS="-undefined dynamic_lookup -Wl,-no_fixup_chains"` | Lets Python symbols resolve at runtime instead of statically, and keeps that compatible with newer macOS "chained fixups" linking |
| `-DCMAKE_INSTALL_PREFIX="$VIRTUAL_ENV"` | Installs straight into the venv's site-packages, no manual symlinking |
| `-DCMAKE_INSTALL_RPATH="$VIRTUAL_ENV/lib"` + `-DCMAKE_BUILD_WITH_INSTALL_RPATH=ON` | Lets `freenect.so` actually find `libfreenect_sync.dylib` at import time |
| CMakeLists.txt edit above | The actual crash fix — stops a second CPython from getting linked into the module |

Sanity-check the driver on its own before involving Flask:

```python
import freenect
rgb, _ = freenect.sync_get_video()
print(rgb.shape)   # expect (480, 640, 3)
```

If that raises a USB permissions/access error, unplug and replug the
Kinect (it needs both USB and its separate power supply connected) and
try again; on first connect macOS may also prompt for a permission
dialog you need to approve.

## 3. Run against real hardware

```
python app.py
```

## Files

- `kinect_capture.py` — thin wrapper around `freenect.sync_get_video()` /
  `sync_get_depth()`, plus the raw-disparity-to-millimetres conversion
  and the `SimulatedKinectSource` fallback.
- `app.py` — background capture thread + Flask routes: `/rgb_feed` and
  `/depth_feed` as MJPEG streams, `/stats` for frame rate and nearest
  point, `/` for the page.
- `templates/index.html` — two-panel page, polls `/stats` once a second.

## Notes

- Depth is requested in the sensor's native 11-bit raw format and
  converted to millimetres with the standard community-derived formula
  (documented in `kinect_capture.py`); it hasn't been checked against a
  hand-measured distance yet, since testing so far has been simulate-mode
  only — worth a quick sanity check once the sensor is attached, the same
  way as with the Hokuyo tool.
- The depth panel uses a fixed 0.4–4.0 m colour scale (`COLORMAP_TURBO`)
  rather than auto-ranging per frame, so distances stay visually
  comparable across frames. Adjust the clamp range in `_depth_to_jpeg()`
  in `app.py` if your setup needs a different working distance.
- RGB and depth are pulled independently and aren't guaranteed
  frame-synchronised; fine for a live view, not for anything that needs
  precise RGB-depth correspondence.

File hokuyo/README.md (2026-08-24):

# Hokuyo URG-04LX-UG01 live visualiser

Standalone Flask + SSE dashboard for the Hokuyo scanning rangefinder.
Not wired into the UniProto Arduino stream — this talks straight to the
sensor over its own USB serial port.

## Setup (macOS)

```
python3 -m venv venv
source venv/bin/activate
pip install -r requirements.txt
```

## Run

Try it without hardware first:

```
python app.py --simulate
```

Open http://127.0.0.1:5001 — you should see a synthetic scan sweeping and
breathing so you can check the layout and HUD before touching the sensor.

With the sensor plugged in, find its port:

```
ls /dev/tty.usbmodem*
```

then:

```
python app.py --port /dev/tty.usbmodem1234
```

## Files

- `hokuyo_driver.py` — SCIP 2.0 protocol driver (serial I/O, GD/MD commands,
  distance decoding). No hardware to test against here, so **the first
  live run should be sanity-checked**: point the sensor at a wall you've
  measured by hand and confirm the "nearest point" reading on the
  dashboard agrees before trusting anything further downstream.
- `app.py` — background reader thread + Flask routes (`/` for the page,
  `/stream` for the SSE scan feed).
- `templates/index.html` — canvas polar plot, HUD (nearest point, scan
  rate, point count), all client-side JS, no build step.

## Notes

- Default serial settings: 115200 baud, matching the sensor's USB-CDC
  default. If `HokuyoURG(...)` raises on connect, check the port path
  is right and that nothing else (e.g. a leftover `screen` session) has
  it open.
- The scan uses cluster_count=0 (full resolution, no on-sensor
  averaging) across the full 682-point, 240 degree sweep (steps 44–725).
- If the plotted shape looks mirrored versus the room, flip the sign in
  `polarToXY()` in `index.html` — that's a display convention, not a
  data problem.
- If a previous run was stopped uncleanly (Ctrl+C without it shutting
  down, a crash), the sensor can be left mid continuous-scan and won't
  respond correctly to a fresh connect. Unplugging and replugging the
  sensor resets it and clears this.

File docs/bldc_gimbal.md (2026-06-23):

# BLDC Gimbal Motor — Setup & Operation Manual

This document describes the hardware setup, firmware architecture, and operation
of the BLDC gimbal motor haptic controller built with a DRV8313 three-phase
driver, AS5600 absolute magnetic encoder, and a custom minimal FOC implementation
running on Arduino Uno.

---

## Hardware

### Components

| Component | Part | Notes |
|---|---|---|
| Motor | BDUA 2204 gimbal motor | 7 pole pairs, >10Ω winding resistance |
| Driver | LittleFOC board (DRV8313) | 3-PWM input, 8–30V motor supply |
| Encoder | AS5600 | 12-bit absolute magnetic, I2C |
| Magnet | 4mm diametric disc | Mounted centred on motor shaft |
| Controller | Arduino Uno | ATmega328P, custom minimal FOC |

### Wiring

```
Arduino         LittleFOC (DRV8313)     Motor
─────────────────────────────────────────────────
Pin 9  ──────── IN1                     Phase A (M1)
Pin 10 ──────── IN2                     Phase B (M2)
Pin 11 ──────── IN3                     Phase C (M3)
Pin 8  ──────── EN (enable, HIGH=active)
5V     ──────── SLEEP (always active)
5V     ──────── RESET (never reset)
GND    ──────── GND
[8–30V]──────── VCC (motor supply)

Arduino         AS5600
─────────────────────
A4     ──────── SDA
A5     ──────── SCL
3.3V   ──────── VCC
GND    ──────── GND
[diametric magnet centred on shaft above sensor]
```

> **Note:** SLEEP and RESET on the LittleFOC board have onboard pull-up
> resistors — leave unconnected. Only EN needs to be driven from Arduino.

---

## System Architecture

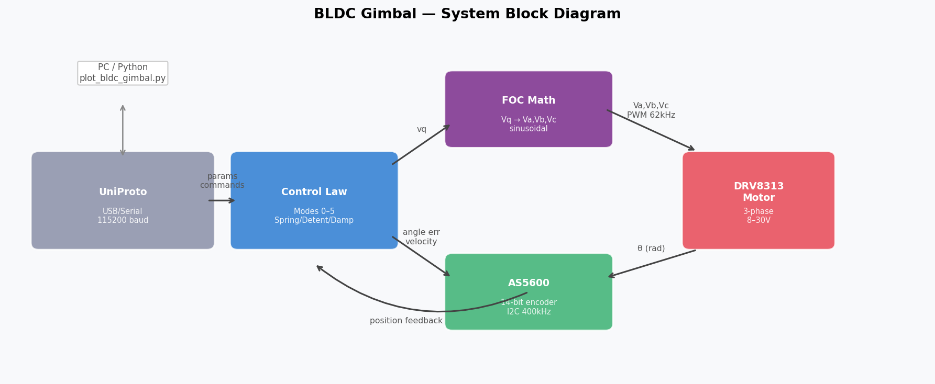
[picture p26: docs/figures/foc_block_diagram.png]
Block diagram


The system has three layers:

1. **UniProto** handles USB serial communication at 115200 baud. The Python
   visualiser sends parameter updates (`!param:value`) and reads the streaming
   telemetry (position, velocity, effort, raw encoder count).

2. **Control law** computes the torque demand `Vq` from the current position
   error and velocity, according to the selected control mode (0–5).

3. **FOC math** converts `Vq` and the electrical angle into three sinusoidal
   PWM voltages that drive the DRV8313 half-bridges.

### FOC Implementation

Field Oriented Control in voltage mode:

```
θ_elec = −angle × pole_pairs        (negated to match phase wiring)

Va = Vq × sin(θ_elec)
Vb = Vq × sin(θ_elec + 120°)
Vc = Vq × sin(θ_elec + 240°)

PWM = (V / Vsupply + 0.5) × 255    clamped to 0–255
```

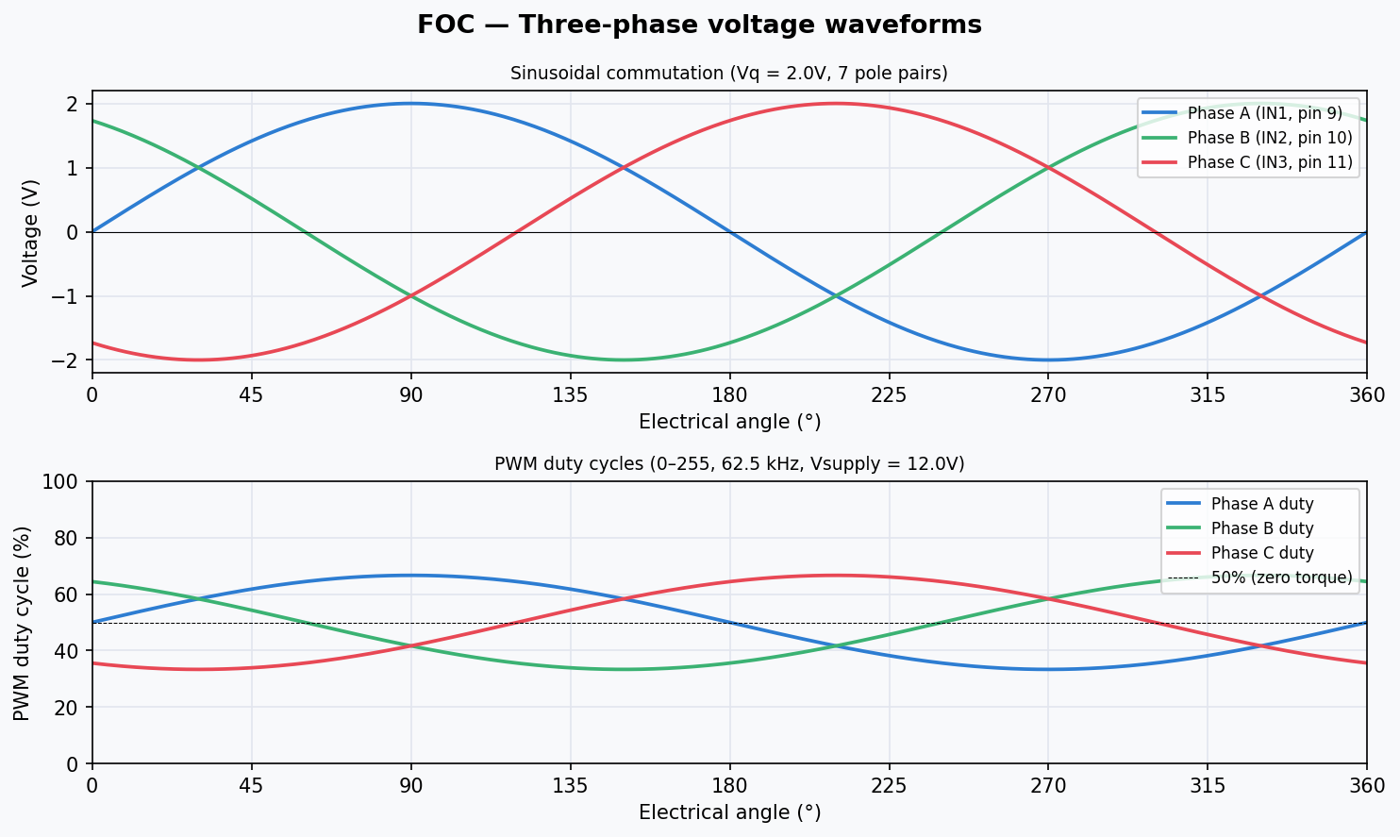
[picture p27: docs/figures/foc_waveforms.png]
FOC waveforms


The three phases are generated at **62.5 kHz** (Timer1 ICR1=255, Timer2
prescale=1) — well above the audible range, giving silent operation. All
three phases use identical 0–255 PWM range to ensure symmetric torque in
both rotation directions.

### Encoder

The AS5600 ANGLE register (0x0C) gives a 12-bit value (0–4095) per
revolution. The firmware reads this via I2C at 400 kHz on every loop
iteration. The raw reading is unwrapped into a continuously accumulating
`_angle` variable using shortest-arc differencing:

```cpp
diff = raw - _prev;                        // may wrap
while (diff >  π) diff -= 2π;             // unwrap to ±π
while (diff < -π) diff += 2π;
diff = -diff;                              // CW = positive angle
_angle += diff;
```

`_angle` starts at 0 on every power-on (the first reading initialises
`_prev`, making the first `diff ≈ 0`). Use `@foc.zero` to re-zero at any
time during operation.

---

## Control Modes

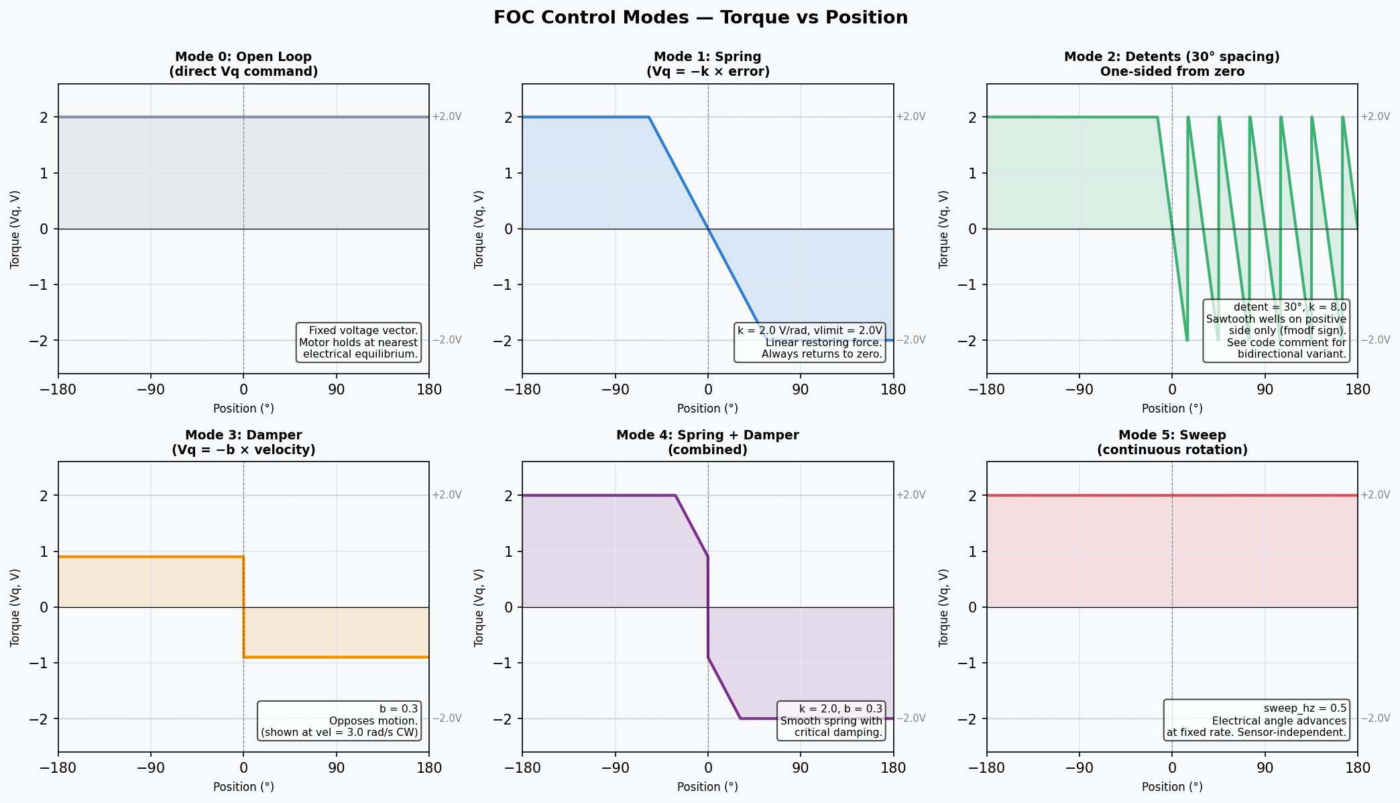
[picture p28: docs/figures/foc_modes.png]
Control modes


### Mode 0 — Open Loop

```
Vq = foc.vq    (constant, set by user)
```

The electrical angle is fixed at `foc.theta`. The motor snaps to the
nearest stable electrical position and holds. Used for diagnostics and
pole-pair counting: count the number of stable positions per mechanical
revolution — that number is your pole pairs.

### Mode 1 — Spring

```
Vq = −k × (angle − set)
```

Linear restoring force proportional to angular displacement from `foc.set`.
Force is unbounded — the motor will pull back from any number of full
revolutions. Increase `foc.k` for a stiffer spring, `foc.vlimit` for more
maximum torque.

### Mode 2 — Detents

```
phase = (angle − set + detent/2) mod detent − detent/2
Vq = −detent_k × phase
```

Creates repeating sawtooth potential wells spaced `foc.detent` radians
apart (default 30° = π/6). The motor clicks between fixed positions like
a mechanical encoder. `foc.detent_k` controls the sharpness of each click.

### Mode 3 — Damper

```
Vq = −b × velocity
```

Opposes angular velocity in both directions, creating a viscous drag
sensation. Works symmetrically for CW and CCW. Use with mode 4 for a
critically damped spring, or alone for a smooth flywheel feel.

### Mode 4 — Spring + Damper

```
Vq = −k × (angle − set) − b × velocity
```

Combines spring restoring force with velocity damping. With appropriate
`foc.b`, eliminates oscillation on release (critically damped). Start
with `b ≈ 0.3` and increase until overshoot disappears.

### Mode 5 — Sweep

```
θ_elec advances at sweep_hz electrical revolutions/sec
```

Continuous rotation test. Positive `foc.sweep_hz` = CW, negative = CCW.
The motor rotates continuously at a rate controlled by `sweep_hz`,
independent of the position sensor. Used to verify the driver and wiring
before tuning closed-loop modes.

---

## Quick Start

### 1. Flash firmware

```bash
pio run -e bldc_gimbal -t upload
```

### 2. Launch visualiser

```bash
python readers/plot_bldc_gimbal.py --port /dev/tty.usbmodemXXXX
```

### 3. Verify encoder

Stream position without enabling the motor. Turn the shaft by hand and
confirm `pos` increases CW and decreases CCW.

### 4. Test sweep (open-loop rotation check)

```
enable → mode 5 sweep → ▶ 0.5
```

Motor should spin CW at a steady rate. `◀ −0.5` should spin CCW at the
same speed. If CW and CCW speeds differ, adjust `foc.ph` (phase offset)
in ±π/4 increments until they match.

### 5. Spring mode

```
mode 1 spring → @foc.zero → k 2.0 → vlimit 2V
```

Turn the rotor and release — it should spring back to zero smoothly from
any position in either direction. If it spins away instead of returning,
swap any two motor phase wires (M1 ↔ M2) and reflash.

---

## Parameter Reference

| Parameter | Default | Description |
|---|---|---|
| `foc.enable` | 0 | 0=off, 1=on (also drives EN pin) |
| `foc.mode` | 1 | Control mode 0–5 (see above) |
| `foc.poles` | 7 | Motor pole pairs |
| `foc.vsupply` | 12.0 | Motor supply voltage (V) |
| `foc.vlimit` | 2.0 | Max torque voltage (V), start low |
| `foc.k` | 2.0 | Spring stiffness (V/rad) |
| `foc.b` | 0.3 | Damping coefficient (V·s/rad) |
| `foc.set` | 0.0 | Spring/detent setpoint (rad) |
| `foc.detent` | 0.5236 | Detent spacing (rad), default 30° |
| `foc.detent_k` | 8.0 | Detent well stiffness |
| `foc.vq` | 2.0 | Open-loop torque command (V) |
| `foc.theta` | 0.0 | Open-loop fixed electrical angle (rad) |
| `foc.sweep_hz` | 0.5 | Sweep rate (elec. rev/s), +ve=CW |
| `foc.ph` | 0.0 | Electrical phase offset for symmetry tuning |
| `foc.pos` | — | Read-only: current angle (rad) |

### Actions

| Action | Description |
|---|---|
| `@foc.zero` | Reset `_angle` and `_set` to 0 at current position |

---

## Tuning Guide

### Finding pole pairs

Use mode 0 (open loop):
```
!foc.mode:0
!foc.vq:2.0
!foc.enable:1
!foc.theta:0.0
```
Count how many stable positions you feel per full revolution. That number
is your pole pairs. Alternatively: enable sweep and compare how far the
shaft moves per electrical revolution (`foc.theta` from 0 to 2π).

### Spring feel

| Parameter | Effect |
|---|---|
| `foc.k` ↑ | Stiffer, snappier return |
| `foc.vlimit` ↑ | More maximum force |
| `foc.b` ↑ | More damping, less oscillation |
| `foc.k` > 5 with low `foc.b` | Oscillation / instability |

Start: `k=2.0, vlimit=2.0, b=0.3`. Increase `k` to taste, then increase
`b` if oscillation appears.

### Detent feel

| Parameter | Effect |
|---|---|
| `foc.detent` | Spacing between clicks (rad) |
| `foc.detent_k` ↑ | Sharper, more defined click |
| `foc.vlimit` ↑ | Stronger holding force in each well |

Common detent spacings: 30° = 0.5236 rad, 45° = 0.7854 rad, 
15° = 0.2618 rad.

---

## Troubleshooting

| Symptom | Likely cause | Fix |
|---|---|---|
| Motor spins to infinity in spring mode | Wrong torque sign | Swap two motor phase wires |
| N stable points in open-loop (mode 0) | Wrong pole pairs | `!foc.poles:N` |
| CW and CCW sweep speeds differ | Phase waveform asymmetry | Adjust `!foc.ph:0.785` etc. |
| Audible hum | PWM frequency too low | Check Timer1/2 setup in firmware |
| Cogging, snapping at fixed intervals | Natural motor cogging | Normal; reduce vlimit if severe |
| Spring works one way, not the other | `_start_offset` bug (old firmware) | Update to latest firmware |
| Encoder only spans π/2 per revolution | Wrong magnet type | Use diametric disc magnet |
| AS5600 not found (WARN on boot) | I2C wiring error | Check SDA/SCL, pull-ups |

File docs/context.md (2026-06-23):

# UniProto — Context & Decision Log

Running log of bugs found, decisions made, and lessons learned across
development sessions.

---

## Architecture Decisions

### PlatformIO multi-environment structure
`src_dir = .` in `[platformio]` (not in `[env:*]`) with per-env
`build_src_filter = -<*> +<src_name/>` resolves "undefined reference to
setup/loop" and "Nothing to build" errors when sharing a repo across setups.

### Binary framing
`w.begin(sid, payloadLen)` requires an explicit payload length. Omitting it
(using default `payloadLen=0`) silently no-ops all subsequent field writes.
Payload length = sum of all field byte sizes: u16=2, i32=4, f32=4, u8[N]=N.

### EU grading formula (rubric tools)
`grade = 1 + 9 × (earned / max)`

---

## Python Reader Patterns

### Non-blocking serial
```python
ser = serial.Serial(port, baud, timeout=0.0)
time.sleep(2.0); ser.reset_input_buffer()
# in loop:
waiting = ser.in_waiting
if waiting: rxbuf += ser.read(waiting)
```

### Parse-first receive
Try comma-split and int/float parse; if fails → log as text. Never
pre-filter on first character — negative CSV values start with `-`
which fails `.isdigit()`.

```python
parts = [p.strip() for p in line.split(",")]
if len(parts) != N:
    log(f"  {line}")   # text response
    continue
try:
    val = float(parts[0])
    ...
except ValueError:
    log(f"  {line}")
    continue
```

### Matplotlib Button GC
Buttons created in loops must be stored in a list:
```python
_btns = []
for ...:
    b = Button(...)
    b.on_clicked(...)
    _btns.append(b)   # ← essential, prevents GC killing event handlers
```

### TextBox double-fire
`on_submit` fires on both Enter keypress and focus-loss. Use a simple
debounce or just accept the duplicate (Arduino ignores repeated same command).

### Matplotlib redraw at fixed interval
```python
last_draw = time.time()
if new_data and (now - last_draw) >= 0.04:
    last_draw = now; new_data = False
    # update plots
    fig.canvas.draw_idle(); fig.canvas.flush_events()
else:
    plt.pause(0.005)
```

---

## Sensor-Specific Notes

### HX711 (load_cell, kitchen_scales)

- **Wrong param prefix bug:** `defaultUno2()` sets `prefix="hx2"`. Override
  with `c.prefix = "hx"` in `makeCfg()` if you only want `hx.*` params.
- **Blocking reads stall serial:** `readAvg(4)` at 100ms per sample = 400ms
  blocking per emit. Fix: non-blocking `readOnce()` in emit (returns stale
  if DOUT not ready); averaging via accumulator in `poll()` called from `loop()`.
- **TextBox double-fire:** see above.
- **Non-data responses swallowed:** receive loop only parsed 2-field CSV lines.
  Fix: parse-first pattern above.
- **Negative value gating:** `line[0].lstrip("-").isdigit()` incorrectly
  rejects negative CSV values. Fix: parse-first, classify by parse failure.

### AS5600 + BLDC Gimbal

- **Magnet range:** 4mm diametric disc magnet gives 12-bit range (0–4095)
  not 14-bit (0–16383). Scale: `raw / 4095.0 * 2π`.
- **Startup zero:** initialise `_prev` to first AS5600 reading so `_angle`
  starts at 0 naturally. Do NOT subtract a `_start_offset` — this creates
  spurious wraps when the raw reading crosses zero, corrupting `_angle` by
  ±2π and causing the spring to push away instead of pull back.
- **FOC on Uno:** SimpleFOC exceeds 32KB flash (33.9KB). Custom minimal
  FOC implemented instead.
- **PWM symmetry:** Timer1 (pins 9,10) must use same range as Timer2 (pin 11).
  Set `ICR1=255` so all three phases use 0–255 — otherwise phase C has half
  the resolution and the three-phase symmetry breaks, creating a preferred
  rotation direction.
- **Electrical angle negation:** with `diff = -diff` (CW=positive mechanical),
  electrical angle must be `-_angle * poles` to produce symmetric torque.
  Spring `vq = -k * err` is then correct (negative vq when error is positive).
- **Pole pairs (BDUA 2204):** 7 pole pairs confirmed by open-loop stable
  point count and 1/7-revolution-per-electrical-revolution sweep test.
- **Sweep direction:** with negated electrical angle, `_th_open -= sweep_hz * dt`
  gives CW = positive `sweep_hz`.
- **Phase offset `foc.ph`:** adjustable to compensate for minor CW/CCW
  speed asymmetry in sweep mode.

### Cap sense (Duemilanove 168)

- Board ID: `diecimilaatmega168` (not `diecimila`)
- Only 14KB flash / 1KB RAM → reduced UniProto limits in build flags
- `_delay_us` is a reserved function name in AVR libc. Rename to `_chargeUs`.
- 200pF + 10MΩ: τ = 2ms. Mode 0 at 200µs charge delay works well.
- Non-linear range or sudden drop to zero: check for bent rotor plate
  (shorting stator). Confirmed fix: bend plate back with toothpick.

### Synchro transformer

- Timer2 used for 5kHz ISR (not PWM output). Timer0/Timer1 set for
  fast PWM on phase output pins.
- Timer0 prescaler change (`TCCR0B = 1`) breaks `millis()` — UniProto's
  rate limiter is affected but communication still works.
- Binary framing required for frame data. Startup sequence must silence
  stream first (`!stream:0`) before switching format.
- `w.begin(sid)` with no payload length silently drops all data in binary
  mode. Must pass explicit `payloadLen = 3*2 + count`.
- Angle cross-correlation: torn-read race between ISR writing `_capture[]`
  and main loop reading it. Angle values erratic. TODO: double-buffer.

### MMA7260 accelerometer

- SLEEP, GS1, GS2 must be driven as digital outputs before sensor works.
- g-select: GS1=0, GS2=0 → ±1.5g, 800mV/g, Vzero=1.65V.
- `atan2` for pitch/roll (not `asin`): `asin` compresses large angles
  by ~6×. `atan2(gx, sqrt(gy²+gz²))` gives correct ±90° range.
- Matplotlib button GC bug affected avg/rate buttons in loop — fixed with
  `_rate_btns = []` / `_avg_btns = []` lists.

---

## BLDC Gimbal — Debugging Chronicle

Long debug trail worth documenting to avoid repeating.

1. **M5Stack DRV11873** — wrong driver. Sensorless BEMF trapezoidal,
   minimum speed required. Unsuitable for gimbal.
2. **SimpleFOC** — too large for Uno (33.9KB > 32KB). Custom FOC written.
3. **38400 baud** — left over from original Processing sketch. Changed to
   115200 to match rest of project. Was causing "no response" symptom.
4. **Binary framing** — `w.begin(sid)` with no payload length silently
   dropped all data. Fixed by passing explicit `payloadLen`.
5. **PWM asymmetry** — Timer1 using `ICR1=511` (0–511 range) while Timer2
   used 0–255. Caused preferred rotation direction. Fixed: `ICR1=255`.
6. **`_start_offset` bug** — subtracting startup position from raw reading
   caused a spurious `±2π` jump in `_angle` whenever the raw sensor crossed
   zero, depending on startup position. Spring then applied wrong-direction
   force at that angular position. Fixed: removed `_start_offset` entirely;
   initialise `_prev` to first reading instead.
7. **Electrical angle sign** — with CW=positive `_angle` (via `diff = -diff`),
   must use `-_angle * poles` for electrical angle. Spring `vq = -k * err`
   is then correct. Sweep uses `_th_open -= sweep_hz * dt`.
8. **Pole pairs** — confirmed 7 by two methods: open-loop stable point count
   (4 originally confused us, but was actually TWO separate issues at once),
   and 1/7-revolution per electrical sweep.

---

## TODO

- [ ] **bldc_gimbal:** Verify spring symmetry after latest firmware fixes
- [ ] **bldc_gimbal:** Tune spring/damper, step response testing
- [ ] **bldc_gimbal:** Implement detent mode verification
- [ ] **synchro:** Fix angle cross-correlation torn-read race (double-buffer)
- [ ] **wind_speed:** Add pulse counting for calibrated flow measurement
- [ ] **kitchen_scales:** Verify calibration after parser fixes
- [ ] **readers/unistream.py:** Extract common serial boilerplate
- [ ] Apply parse-first pattern to `plot_cap_sense.py` and `plot_wind_raw.py`
- [ ] **NAO robot:** USB recovery flash to NAOqi 2.1 (Project Glasswing pending)
- [ ] **DRV8313 SimpleFOC on Mega:** mod_simplefoc wrapper when hardware arrives

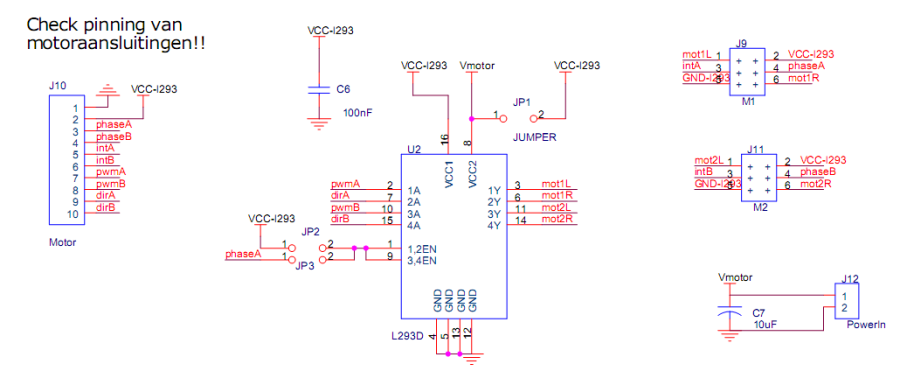
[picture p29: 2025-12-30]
docs/figures/l293.png

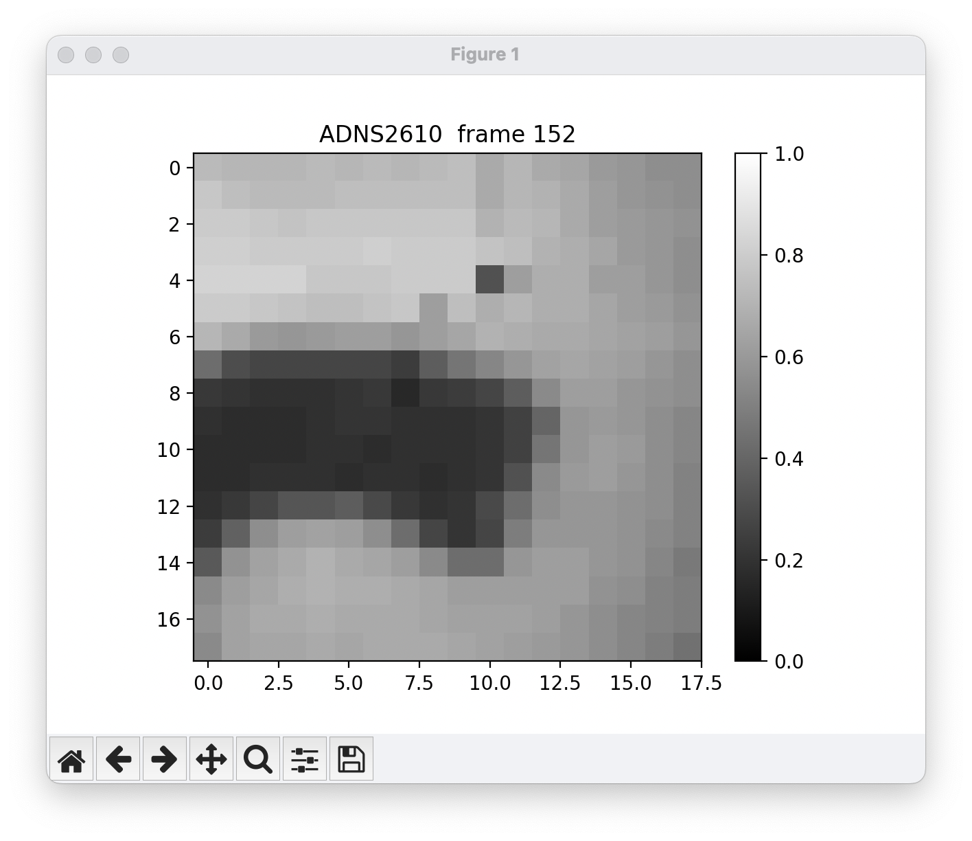
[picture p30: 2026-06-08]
docs/figures/adns.png

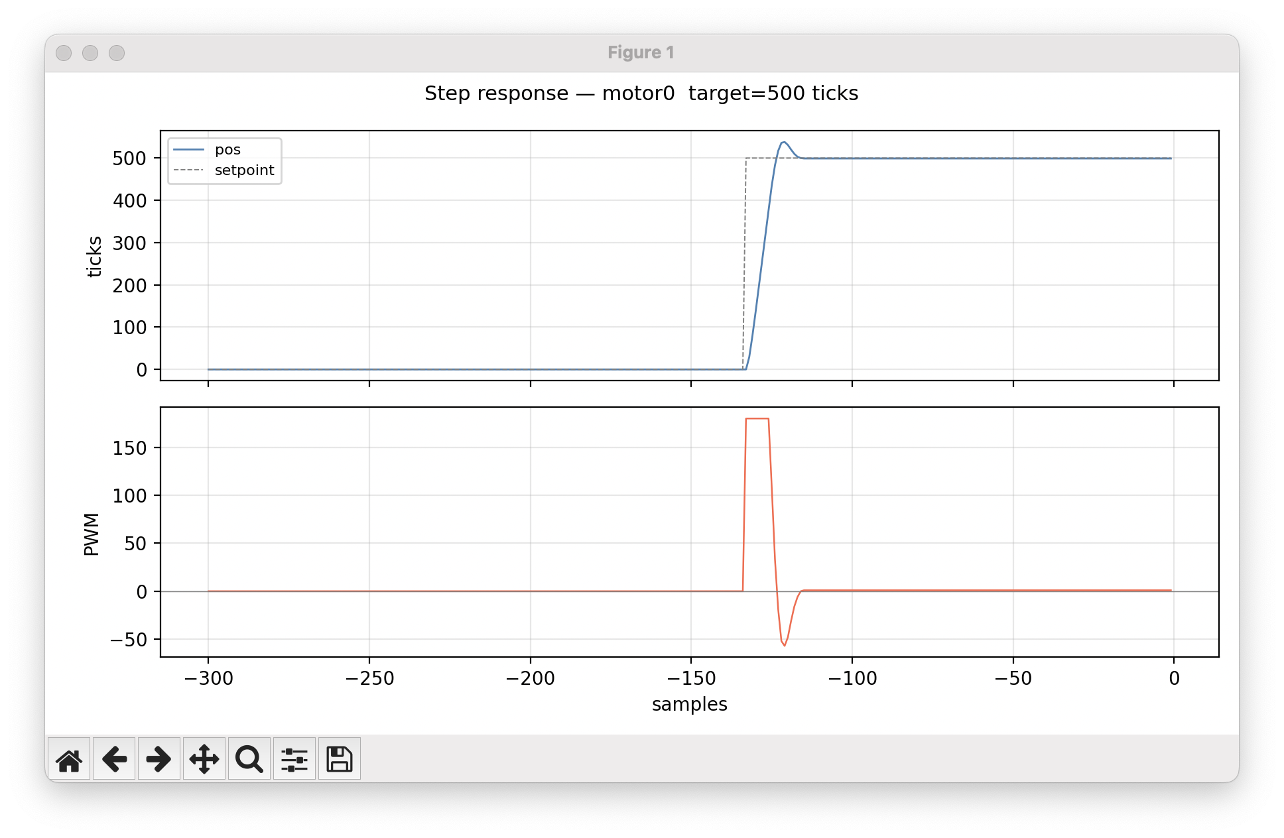
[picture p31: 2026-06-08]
docs/figures/dualmotorstepresponse.png

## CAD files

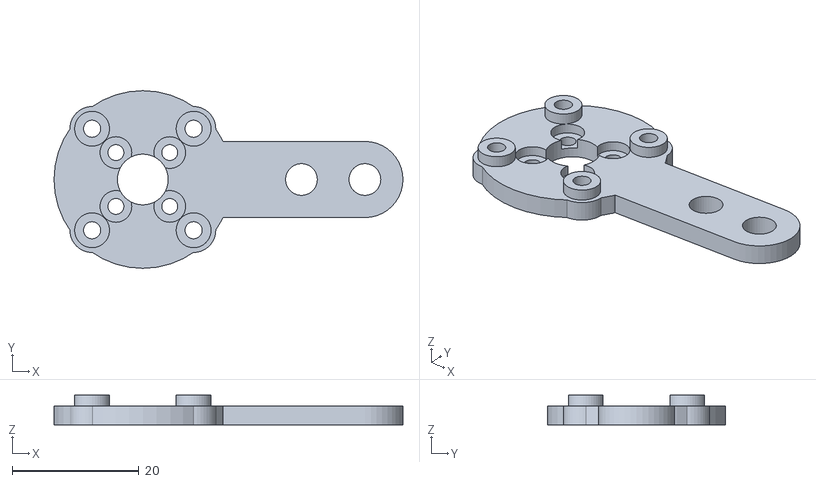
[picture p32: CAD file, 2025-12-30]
design/bldc/motorholder.stl
55.0 x 28.0 x 4.70

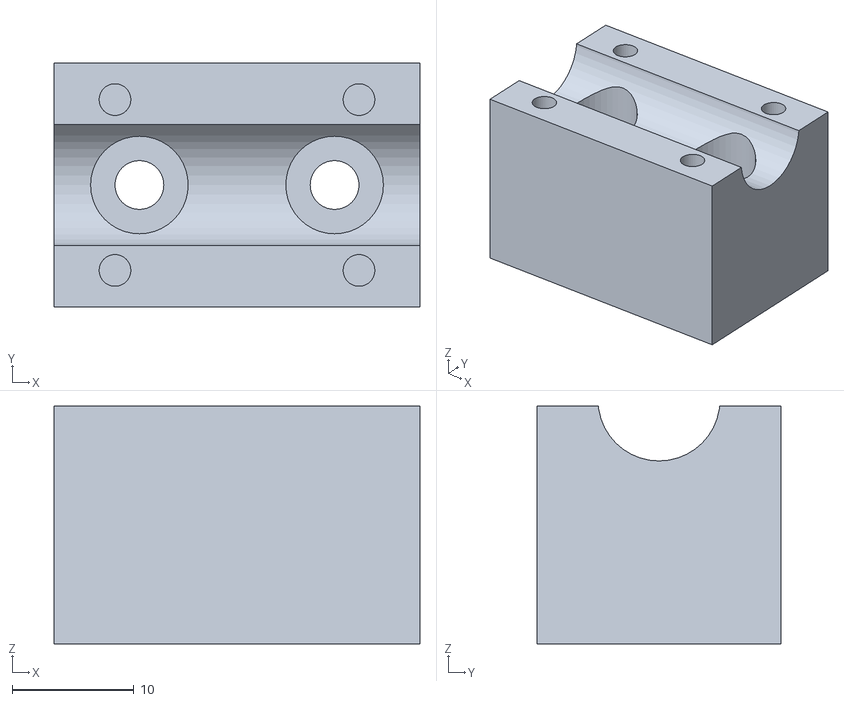
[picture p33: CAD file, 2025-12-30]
design/dualmotor/motor-block-bottom.stl
30.0 x 20.0 x 19.5

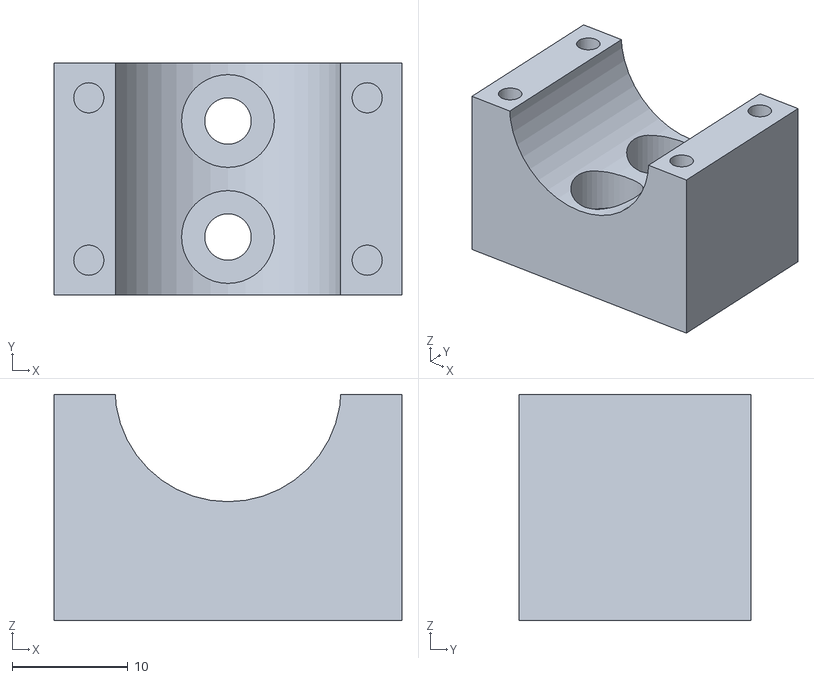
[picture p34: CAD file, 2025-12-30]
design/lvdt/lvdtmount-bot.stl
30.0 x 20.0 x 19.5

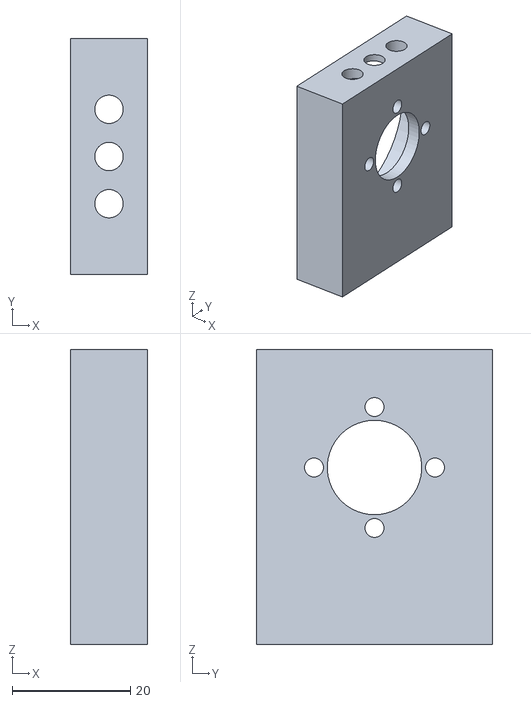
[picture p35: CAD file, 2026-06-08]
design/synchro/synchro.stl
13.0 x 40.0 x 50.0

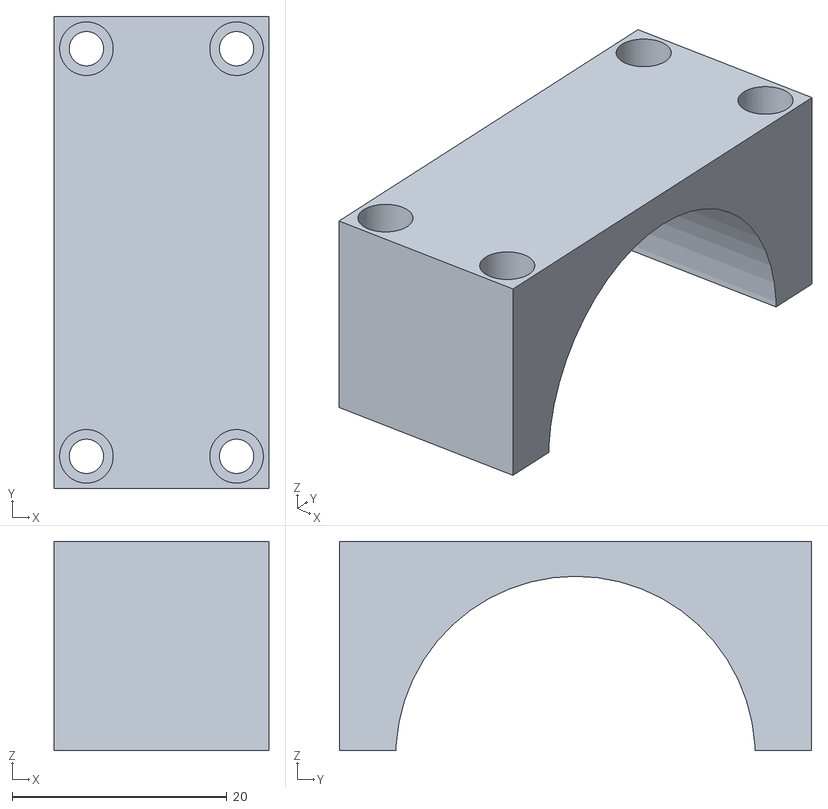
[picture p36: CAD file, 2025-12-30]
design/windsensor/top.stl
20.0 x 44.0 x 19.5

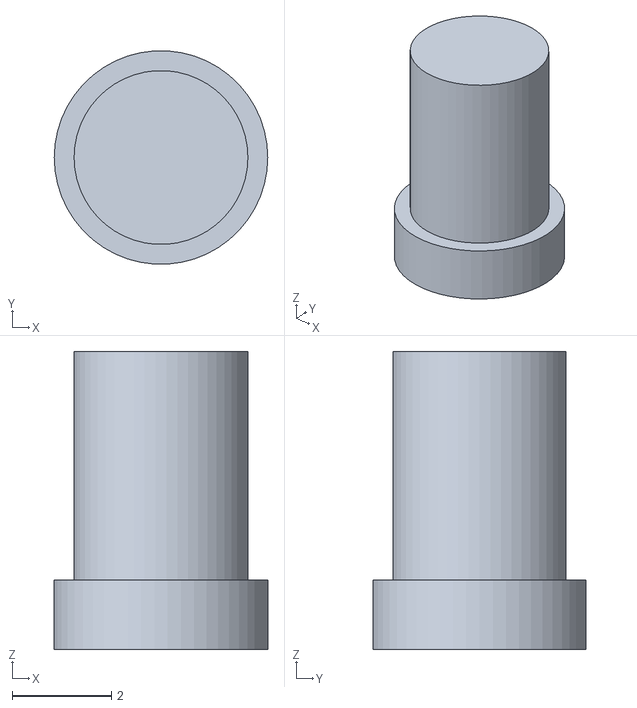
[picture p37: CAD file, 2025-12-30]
design/bldc/magnetholder.stl
4.30 x 4.29 x 6.00

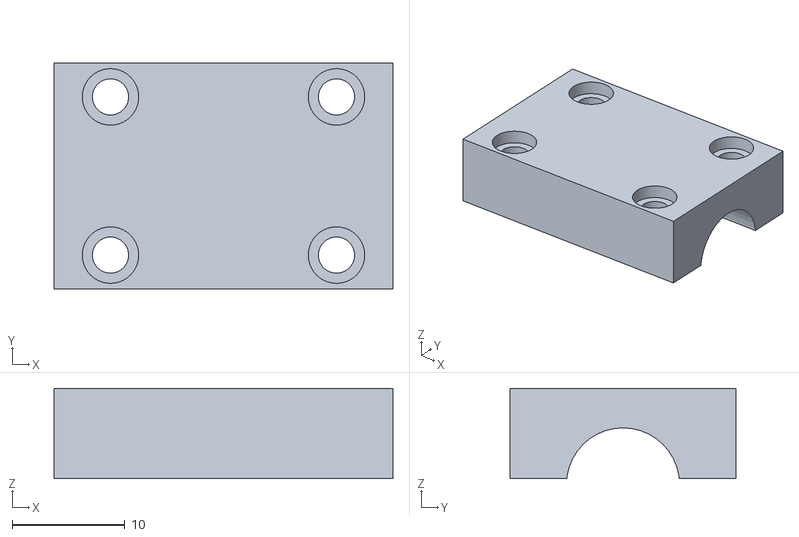
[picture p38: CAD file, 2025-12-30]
design/dualmotor/motor-block-top.stl
30.0 x 20.0 x 8.00

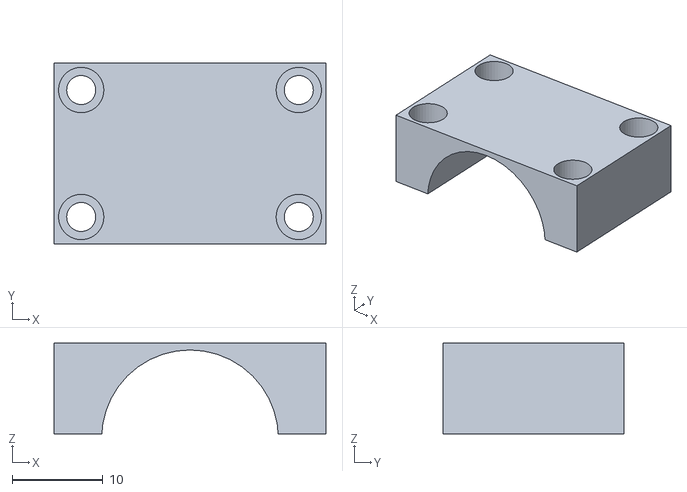
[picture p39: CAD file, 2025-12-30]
design/lvdt/lvdtmount-top.stl
30.0 x 20.0 x 10.0

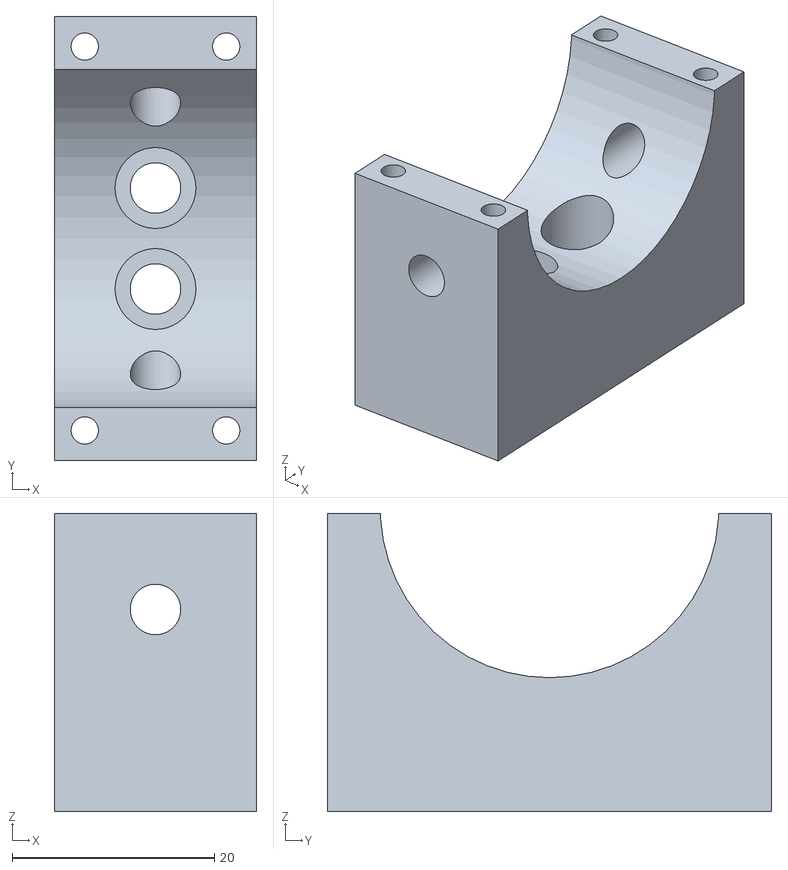
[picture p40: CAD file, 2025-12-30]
design/windsensor/base.stl
20.0 x 44.0 x 29.5

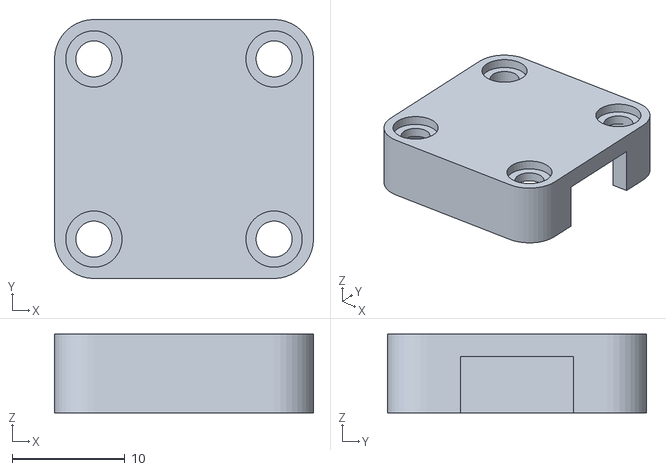
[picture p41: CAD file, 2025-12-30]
design/bldc/cover.stl
23.0 x 23.0 x 7.00

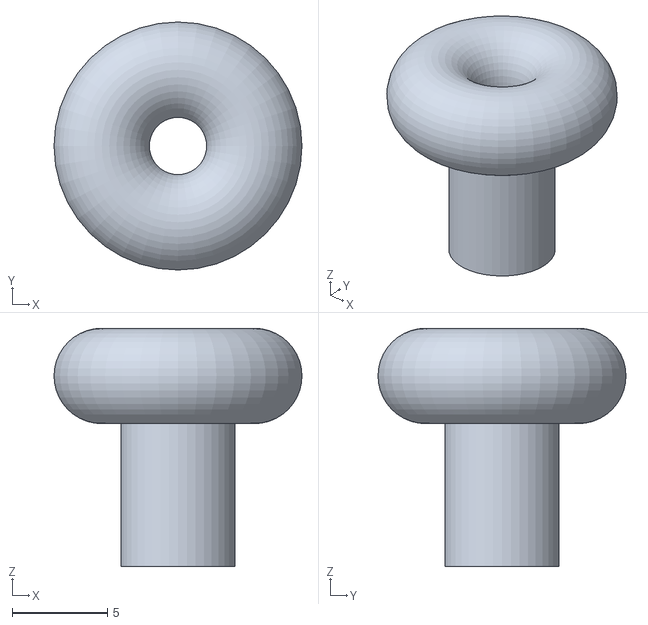
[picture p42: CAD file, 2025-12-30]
design/bldc/smalltop.stl
13.0 x 13.0 x 12.5

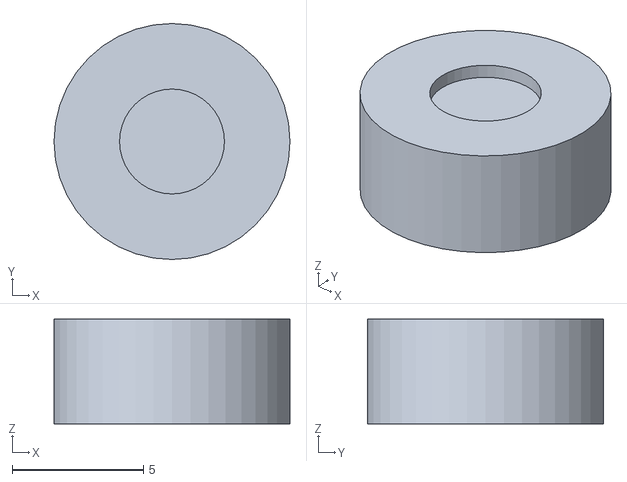
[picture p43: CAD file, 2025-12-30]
design/bldc/centerhelp.stl
9.00 x 9.00 x 4.00

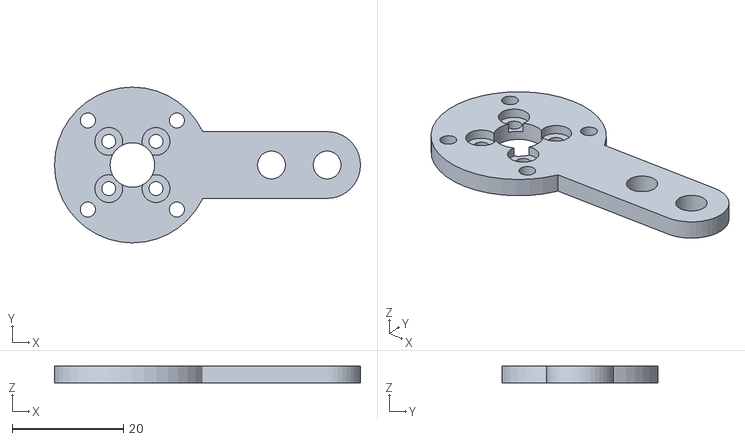
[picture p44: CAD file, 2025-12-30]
design/bldc/top.stl
55.0 x 28.0 x 3.00

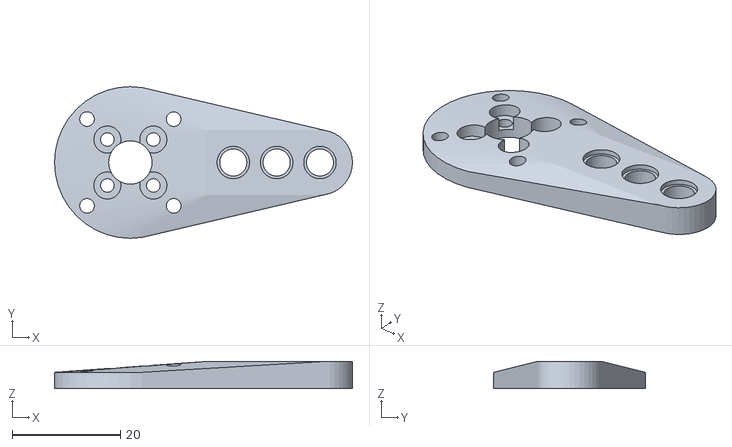
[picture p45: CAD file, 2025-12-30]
design/bldc/holder.stl
55.0 x 28.0 x 5.00

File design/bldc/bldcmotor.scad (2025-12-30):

$fn = 40;
//centerhelp();
//holder();
//cover();
bottom();
module cover(){
difference(){
    hull(){
    translate([-8,-8,0])cylinder(d=7,h=7);
    translate([8,-8,0])cylinder(d=7,h=7);
    translate([8,8,0])cylinder(d=7,h=7);
    translate([-8,8,0])cylinder(d=7,h=7);
    }
    translate([-8,-8,0])cylinder(d=3.2,h=8);
    translate([8,-8,0])cylinder(d=3.2,h=8);
    translate([8,8,0])cylinder(d=3.2,h=8);
    translate([-8,8,0])cylinder(d=3.2,h=8);
    translate([0,-5,0])cube([20,10,5]);
    
                translate([-8,-8,6])cylinder(d=5,h=5);
    translate([8,-8,6])cylinder(d=5,h=5);
    translate([8,8,6])cylinder(d=5,h=5);
    translate([-8,8,6])cylinder(d=5,h=5);
    
    
    hull(){
            translate([-8,-8,0])cylinder(d=3.2,h=5);
    translate([8,-8,0])cylinder(d=3.2,h=5);
    translate([8,8,0])cylinder(d=3.2,h=5);
    translate([-8,8,0])cylinder(d=3.2,h=5);
    }
    }}

//bottom();
module centerhelp(){difference(){
    cylinder(d=9,h=4);
    translate([0,0,3.5])cylinder(d=4,h=5);
}}

module bottom() {difference(){
union(){
    hull(){cylinder(d=28,h=3);
    translate([14,-6,0])cube([21,12,5]);
    translate([35,0,0])cylinder(d=12,h=5);
        }
    hull(){
    translate([-8,-8,0])cylinder(d=7,h=3);
    translate([8,-8,0])cylinder(d=7,h=3);
    translate([8,8,0])cylinder(d=7,h=3);
    translate([-8,8,0])cylinder(d=7,h=3);
    }
        translate([-8,-8,1])cylinder(d=5.5,h=3.7);
    translate([8,-8,1])cylinder(d=5.5,h=3.7);
    translate([8,8,1])cylinder(d=5.5,h=3.7);
    translate([-8,8,1])cylinder(d=5.5,h=3.7);

}
translate([35,0,0])cylinder(d=5,h=8);
translate([35-8,0,0])cylinder(d=5,h=8);
translate([35-16,0,0])cylinder(d=5,h=8);
translate([35,0,4.2])cylinder(d=6,h=8);
translate([35-8,0,4.2])cylinder(d=6,h=8);
translate([35-16,0,4.2])cylinder(d=6,h=8);
translate([35,0,0])cylinder(d=6,h=0.8);
translate([35-8,0,0])cylinder(d=6,h=0.8);
translate([35-16,0,0])cylinder(d=6,h=0.8);

    cylinder(d=8,h=5);
 rotate([0,0,45])for(i=[0:90:360]){
    rotate([0,0,i]){translate([6,0,0])cylinder(d=2.5,h=5);translate([6,0,1.5])cylinder(d=5,h=5);}
}
    translate([-8,-8,0])cylinder(d=2.7,h=5);
    translate([8,-8,0])cylinder(d=2.7,h=5);
    translate([8,8,0])cylinder(d=2.7,h=5);
    translate([-8,8,0])cylinder(d=2.7,h=5);
}
}





module holder() {difference(){
union(){
    hull(){cylinder(d=28,h=3);
    translate([14,-6,0])cube([21,12,5]);
    translate([35,0,0])cylinder(d=12,h=5);}
}
translate([35,0,0])cylinder(d=5,h=8);
translate([35-8,0,0])cylinder(d=5,h=8);
translate([35-16,0,0])cylinder(d=5,h=8);
translate([35,0,4.2])cylinder(d=6,h=8);
translate([35-8,0,4.2])cylinder(d=6,h=8);
translate([35-16,0,4.2])cylinder(d=6,h=8);
translate([35,0,0])cylinder(d=6,h=0.8);
translate([35-8,0,0])cylinder(d=6,h=0.8);
translate([35-16,0,0])cylinder(d=6,h=0.8);

    cylinder(d=8,h=5);
 rotate([0,0,45])for(i=[0:90:360]){
    rotate([0,0,i]){translate([6,0,0])cylinder(d=2.5,h=5);translate([6,0,1.5])cylinder(d=5,h=5);}
}
    translate([-8,-8,0])cylinder(d=2.7,h=5);
    translate([8,-8,0])cylinder(d=2.7,h=5);
    translate([8,8,0])cylinder(d=2.7,h=5);
    translate([-8,8,0])cylinder(d=2.7,h=5);
}
}

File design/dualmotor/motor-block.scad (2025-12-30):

$fn = 40;
//bottom();
top();
module top(){
difference(){
    translate([0,0,20.5])cube([30,20,8]);
    translate([0,10,20])rotate([0,90,0])cylinder(d=10,h=30);
        translate([5,3,20])cylinder(d=3.2,h=20);
    translate([5,20-3,20])cylinder(d=3.2,h=20);
    
        translate([30-5,3,20])cylinder(d=3.2,h=20);
    translate([30-5,20-3,20])cylinder(d=3.2,h=20);
    
            translate([5,3,27])cylinder(d=5,h=20);
    translate([5,20-3,27])cylinder(d=5,h=20);
    
        translate([30-5,3,27])cylinder(d=5,h=20);
    translate([30-5,20-3,27])cylinder(d=5,h=20);
} 
}
module bottom(){
difference(){
    cube([30,20,19.5]);
    translate([0,10,20])rotate([0,90,0])cylinder(d=10,h=30);
    
    translate([7,10,0])cylinder(d=4,h=30);
    translate([7,10,10])cylinder(d=8,h=30);
    
    translate([30-7,10,0])cylinder(d=4,h=30);
    translate([30-7,10,10])cylinder(d=8,h=30);
    
    translate([5,3,10])cylinder(d=2.6,h=20);
    translate([5,20-3,10])cylinder(d=2.6,h=20);
    
        translate([30-5,3,10])cylinder(d=2.6,h=20);
    translate([30-5,20-3,10])cylinder(d=2.6,h=20);
}}

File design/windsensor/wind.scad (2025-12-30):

$fn=50;
base();

top();
module top(){
difference(){
translate([0,0,30.5])cube([20,44,19.5]);
    translate([0,22,30])rotate([0,90,0])cylinder(d=33.5,h=20);
    
        translate([3,3,30])cylinder(d=3.2,h=33);
    translate([20-3,3,30])cylinder(d=3.2,h=33);
    
    translate([3,44-3,30])cylinder(d=3.2,h=33);
    translate([20-3,44-3,30])cylinder(d=3.2,h=33);
    
            translate([3,3,50-3])cylinder(d=5,h=33);
    translate([20-3,3,50-3])cylinder(d=5,h=33);
    
    translate([3,44-3,50-3])cylinder(d=5,h=33);
    translate([20-3,44-3,50-3])cylinder(d=5,h=33);
}    
}

module base(){
difference(){
    union(){
        cube([20,44,29.5]);
        
    }
    translate([0,22,30])rotate([0,90,0])cylinder(d=33.5,h=20);
    translate([10,0,20])rotate([-90,0,0])cylinder(d=5,h=50);
    
    translate([10,17,0])cylinder(d=5,h=20);
    translate([10,27,0])cylinder(d=5,h=20);
        translate([10,17,8])cylinder(d=8,h=20);
    translate([10,27,8])cylinder(d=8,h=20);
    
    translate([3,3,0])cylinder(d=2.7,h=33);
    translate([20-3,3,0])cylinder(d=2.7,h=33);
    
    translate([3,44-3,0])cylinder(d=2.7,h=33);
    translate([20-3,44-3,0])cylinder(d=2.7,h=33);
}}

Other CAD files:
design/bldc/bottom.stl
design/generic/technic.scad
design/lvdt/lvdtmount.scad
design/synchro/synchro.scad

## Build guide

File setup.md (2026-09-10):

# UniProto sensor readers — setup guide

Quick setup for running the sensor visualisers on macOS, Windows, or Linux.

---

## 1. Prerequisites

- **Python 3.10 or newer** — [python.org](https://www.python.org/downloads/)
- **pip** (comes with Python)
- **Arduino drivers** installed for your board (Uno/Duemilanove: CH340 or FTDI; Leonardo: built-in USB)

---

## 2. Install dependencies

A virtual environment keeps things clean and avoids conflicts with other Python projects.

### macOS / Linux

```bash
cd sensorproto/readers
python3 -m venv .venv
source .venv/bin/activate
pip install -r requirements.txt
```

### Windows

```bat
cd sensorproto\readers
python -m venv .venv
.venv\Scripts\activate
pip install -r requirements.txt
```

After activation your prompt will show `(.venv)`. Run `deactivate` to leave the venv.

### Without a venv (quick and dirty)

```bash
pip install -r requirements.txt
# or: pip3 install -r requirements.txt
```

---

## 3. Finding your serial port

Plug in your Arduino and find its port:

| OS | Command | Typical result |
|---|---|---|
| macOS | `ls /dev/tty.usb*` | `/dev/tty.usbmodem21201` |
| Linux | `ls /dev/ttyACM* /dev/ttyUSB*` | `/dev/ttyACM0` |
| Windows | Device Manager → Ports (COM & LPT) | `COM3`, `COM7`, etc. |

On Linux you may need to add yourself to the `dialout` group:

```bash
sudo usermod -aG dialout $USER
# then log out and back in
```

---

## 4. Run a visualiser

```bash
# macOS / Linux
python plot_sensor_shield.py --port /dev/tty.usbmodem21201

# Windows
python plot_sensor_shield.py --port COM3
```

All scripts accept `--port` and `--baud` (default 115200).

---

## 5. Platform notes

### matplotlib backend

On **macOS**, scripts use the `MacOSX` backend automatically.
On **Windows** and **Linux**, they fall back to `TkAgg`.

If you see `UserWarning: cannot load backend 'MacOSX'` on Linux/Windows — this is expected and handled automatically. If you see a blank window or an error about Tk, install Tkinter:

```bash
# Ubuntu / Debian
sudo apt install python3-tk

# Fedora
sudo dnf install python3-tkinter
```

### pygame (piezo sounds)

If you don't need drum sounds, `pygame` is optional. The `plot_piezo.py` script will run without it (sounds silently disabled). To skip:

```bash
pip install pyserial matplotlib numpy flask
```

### Windows COM port permissions

No special permissions needed on Windows — just ensure the Arduino IDE serial monitor is **closed** before running a Python script (only one process can open a COM port at a time).

### Leonardo on Windows

The Arduino Leonardo uses a composite USB device. Windows 10/11 includes the CDC driver automatically. On Windows 7, you may need to install the driver from the Arduino IDE installation.

---

## 6. All scripts at a glance

| Script | Sensor | Board |
|---|---|---|
| `plot_sensor_shield.py` | Full sensor shield | Uno |
| `plot_sensor_shield_flask.py` | Same, browser view | Uno |
| `plot_sensor_shield_weight.py` | Foil vs strain XY | Uno |
| `plot_sensor_shield_angle.py` | Pot vs Hall angle XY | Uno |
| `plot_bldc_gimbal.py` | BLDC FOC gimbal | Uno |
| `plot_biosensors.py` | GSR + heart rate | Uno |
| `plot_wind_speed.py` | Anemometer | Uno |
| `plot_piezo.py` | Piezo drum pads | Leonardo |
| `plot_dc_motor.py` | DC motor PID | Uno |
| `plot_qtr8.py` | QTR-8RC reflectance | Duemilanove |
| `plot_us_distance.py` | HC-SR04 ultrasonic | Uno |
| `plot_lvdt.py` | LVDT position | Uno |
| `plot_synchro.py` | 3-phase synchro | Uno |
| `plot_dual_motor.py` | Dual motor haptic | Uno |

---

## 7. Updating dependencies

```bash
pip install -r requirements.txt --upgrade
```

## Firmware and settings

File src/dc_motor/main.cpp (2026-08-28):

#include <Arduino.h>
#include "UniProto.h"

// ── DC Motor — Arduino Motor Shield Channel B ─────────────────────────────────
// Single 12V DC motor, 1:30 gearbox, US-Digital 100PPR quadrature encoder.
//
// Motor Shield Channel B:
//   PWM  → pin 11  (Timer2, ultrasonic ~31kHz)
//   DIR  → pin 13
//   BRAKE→ pin 8   (HIGH=brake, LOW=coast)
//
// Encoder (rear shaft, before gearbox):
//   A    → pin 2   (INT0, quadrature)
//   B    → pin 3   (INT1, quadrature)
//   100 PPR × 4 (quadrature) × 30 (gearbox) = 12000 counts/output rev
//
// Potentiometer setpoint (A3=GND, A4=signal, A5=VCC):
//   Provides reference setpoint for position/velocity/PWM modes.
//   A0=Ch.A current sense, A1=Ch.B current sense — used by motor shield,
//   do not connect anything else to A0/A1.
//
// Control modes (!mot.mode):
//   0 = direct PWM   (pot maps ±pwm_lim directly)
//   1 = position PID (pot maps to position setpoint in ticks)
//   2 = velocity PID (pot maps to velocity setpoint in counts/s)
//
// Stream 1 "mot": pos(i32), set(f32), cmd(i32), err(f32), vel(f32), mA(f32)
//   mA = Channel B motor current (A1 sense pin, 2.96mA per ADC count)
//
// Key commands:
//   !mot.mode:1         position control
//   !mot.enable:1       engage controller
//   !mot.kp:2.0         P gain
//   !mot.ki:0.1         I gain
//   !mot.kd:0.05        D gain
//   !mot.pwm_lim:200    max PWM (0-255)
//   !mot.set:6000       set target (ticks — 6000 = 0.5 output rev)
//   !mot.pot_scale:12000 pot range in ticks (position mode)
//   @mot.zero           zero encoder
//   @mot.brake          engage brake
//   @mot.coast          release brake
// ─────────────────────────────────────────────────────────────────────────────

// ── Pins ──────────────────────────────────────────────────────────────────────
#define PIN_PWM   11
#define PIN_DIR   13
#define PIN_BRAKE  8
#define PIN_ENC_A  2
#define PIN_ENC_B  3
#define PIN_POT_GND A3
#define PIN_POT_SIG A4
#define PIN_POT_VCC A5

// ── Encoder ───────────────────────────────────────────────────────────────────
volatile int32_t _enc = 0;

void encISR_A() {
    if (digitalRead(PIN_ENC_A) == digitalRead(PIN_ENC_B)) _enc--; else _enc++;
}
void encISR_B() {
    if (digitalRead(PIN_ENC_A) == digitalRead(PIN_ENC_B)) _enc++; else _enc--;
}

// ── PWM ───────────────────────────────────────────────────────────────────────
// Timer2 fast PWM on pin 11 at ~31kHz (inaudible)
static void setupPWM() {
    TCCR2A = (1<<COM2A1)|(1<<WGM21)|(1<<WGM20);
    TCCR2B = (1<<CS20);   // prescale 1 → 62.5kHz / 2 ≈ 31kHz
    OCR2A  = 0;
    pinMode(PIN_PWM, OUTPUT);
}

static void driveMotor(int16_t cmd) {
    // cmd: -255..+255
    if (cmd >= 0) {
        digitalWrite(PIN_DIR, HIGH);
        OCR2A = (uint8_t)min(cmd, 255);
    } else {
        digitalWrite(PIN_DIR, LOW);
        OCR2A = (uint8_t)min(-cmd, 255);
    }
}

// ── Current sense ─────────────────────────────────────────────────────────────
// Motor Shield: A0=Ch.A current, A1=Ch.B current (our motor is Ch.B)
// 3.3V at pin = 2A → each count = 2.96mA
#define PIN_CS_A  A0
#define PIN_CS_B  A1
static float _current_ma = 0.0f;   // Ch.B motor current in mA

// ── State ─────────────────────────────────────────────────────────────────────
static bool    _enabled   = true;    // start enabled — pot controls position
static uint8_t _mode      = 1;       // 0=PWM, 1=pos PID, 2=vel PID
static float   _kp        = 2.0f;   // P-only to start, safer
static float   _ki        = 0.0f;
static float   _kd        = 0.0f;
static int16_t _pwm_lim   = 100;    // conservative start — increase once working
static float   _set       = 0.0f;
static float   _pot_scale = 12000.0f;
static float   _vel_scale = 20000.0f;

static float    _integral  = 0.0f;
static float    _prev_err  = 0.0f;
static float    _vel       = 0.0f;
static int16_t  _cmd       = 0;
static uint32_t _prev_us   = 0;
static uint16_t _ctrl_hz   = 500;    // control loop rate Hz (default 500)
static uint32_t _ctrl_next = 0;

// ── PID ───────────────────────────────────────────────────────────────────────
static uint32_t _vel_last_us  = 0;
static int32_t  _vel_last_enc = 0;
static float    _vel_alpha    = 0.5f;  // IIR filter: 0=max smooth, 1=raw (off)
#define VEL_WINDOW_US 20000   // compute velocity over 20ms windows

static void updateControl() {
    uint32_t now_us = micros();
    float    dt     = (float)(now_us - _prev_us) * 1e-6f;
    _prev_us = now_us;
    if (dt < 1e-5f || dt > 0.5f) return;

    int32_t pos = _enc;

    // current sense (Ch.B = our motor)
    _current_ma = analogRead(PIN_CS_B) * 2.96f;

    // velocity: only update over minimum window (avoids single-tick noise)
    uint32_t vel_dt_us = now_us - _vel_last_us;
    if (vel_dt_us >= VEL_WINDOW_US) {
        float vel_dt = (float)vel_dt_us * 1e-6f;
        float raw_vel = (float)(pos - _vel_last_enc) / vel_dt;
        _vel = _vel * (1.0f - _vel_alpha) + raw_vel * _vel_alpha;
        _vel_last_us  = now_us;
        _vel_last_enc = pos;
    }

    if (!_enabled) return;

    float err = 0.0f;
    if (_mode == 0) {
        // Direct PWM — pot already mapped to _set in pollPot()
        _cmd = (int16_t)constrain(_set, -_pwm_lim, _pwm_lim);
        driveMotor(_cmd);
        return;
    } else if (_mode == 1) {
        err = _set - (float)pos;
    } else if (_mode == 2) {
        err = _set - _vel;
    }

    _integral += err * dt;
    // Anti-windup: clamp integral
    float max_i = _pwm_lim / max(0.001f, _ki);
    _integral = constrain(_integral, -max_i, max_i);

    float deriv = (err - _prev_err) / dt;
    _prev_err = err;

    float out = _kp * err + _ki * _integral + _kd * deriv;
    _cmd = (int16_t)constrain(out, -_pwm_lim, _pwm_lim);
    driveMotor(_cmd);
}

// ── Potentiometer ─────────────────────────────────────────────────────────────
static void pollPot() {
    int raw = analogRead(PIN_POT_SIG);   // 0-1023
    float norm = (raw / 1023.0f) * 2.0f - 1.0f;  // -1..+1
    if (_mode == 0)      _set = norm * _pwm_lim;
    else if (_mode == 1) _set = norm * _pot_scale;
    else if (_mode == 2) _set = norm * _vel_scale;
}

// ── UniProto ──────────────────────────────────────────────────────────────────
UniProto proto(Serial, "DCMotor");

static void emitMot(UniProto&, uint8_t sid, UniFrameWriter& w, void*) {
    float err = (_mode == 1) ? (_set - (float)_enc)
              : (_mode == 2) ? (_set - _vel)
              : 0.0f;
    w.begin(sid);
    w.i32(_enc,  "pos");
    w.f32(_set,  "set",  1);
    w.i32(_cmd,  "cmd");
    w.f32(err,   "err",  1);
    w.f32(_vel,  "vel",  1);
    w.f32(_current_ma, "mA", 0);
    w.end();
}

static bool getParam(UniProto&, const char* k, char* out, size_t len, void*) {
    if (!strcmp(k,"mot.enable"))    { snprintf(out,len,"%d",_enabled);           return true; }
    if (!strcmp(k,"mot.mode"))      { snprintf(out,len,"%u",_mode);              return true; }
    if (!strcmp(k,"mot.kp"))        { snprintf(out,len,"%.3f",(double)_kp);      return true; }
    if (!strcmp(k,"mot.ki"))        { snprintf(out,len,"%.3f",(double)_ki);      return true; }
    if (!strcmp(k,"mot.kd"))        { snprintf(out,len,"%.3f",(double)_kd);      return true; }
    if (!strcmp(k,"mot.pwm_lim"))   { snprintf(out,len,"%d",_pwm_lim);           return true; }
    if (!strcmp(k,"mot.set"))       { snprintf(out,len,"%.1f",(double)_set);     return true; }
    if (!strcmp(k,"mot.pot_scale")) { snprintf(out,len,"%.0f",(double)_pot_scale);return true;}
    if (!strcmp(k,"mot.vel_scale")) { snprintf(out,len,"%.0f",(double)_vel_scale);return true;}
    if (!strcmp(k,"mot.vel_alpha")) { snprintf(out,len,"%.2f",(double)_vel_alpha);return true;}
    if (!strcmp(k,"mot.pos"))       { snprintf(out,len,"%ld",(long)_enc);        return true; }
    if (!strcmp(k,"mot.vel"))       { snprintf(out,len,"%.1f",(double)_vel);     return true; }
    if (!strcmp(k,"mot.ctrl_hz"))   { snprintf(out,len,"%u",_ctrl_hz);           return true; }
    return false;
}

static bool setParam(UniProto&, const char* k, const char* v, void*) {
    if (!strcmp(k,"mot.enable")) {
        _enabled = UniProto::parseInt(v);
        if (!_enabled) { driveMotor(0); _integral = 0; }
        return true;
    }
    if (!strcmp(k,"mot.mode")) {
        _mode = (uint8_t)UniProto::parseInt(v);
        _integral = 0; _prev_err = 0;
        return true;
    }
    if (!strcmp(k,"mot.kp"))        { _kp        = UniProto::parseFloat(v); return true; }
    if (!strcmp(k,"mot.ki"))        { _ki        = UniProto::parseFloat(v); _integral=0; return true; }
    if (!strcmp(k,"mot.kd"))        { _kd        = UniProto::parseFloat(v); return true; }
    if (!strcmp(k,"mot.pwm_lim"))   { _pwm_lim   = (int16_t)UniProto::parseInt(v); return true; }
    if (!strcmp(k,"mot.set"))       { _set       = UniProto::parseFloat(v); return true; }
    if (!strcmp(k,"mot.pot_scale")) { _pot_scale = UniProto::parseFloat(v); return true; }
    if (!strcmp(k,"mot.vel_scale")) { _vel_scale = UniProto::parseFloat(v); return true; }
    if (!strcmp(k,"mot.ctrl_hz"))   { _ctrl_hz = (uint16_t)constrain(UniProto::parseInt(v),1,5000); _ctrl_next=0; return true; }
    if (!strcmp(k,"mot.vel_alpha")) { _vel_alpha = UniProto::parseFloat(v); return true; }
    return false;
}

static bool doZero(UniProto&, const char*, const char*, Stream& out, void*) {
    noInterrupts(); _enc = 0; interrupts();
    _set = 0; _integral = 0; _prev_err = 0;
    _vel_last_enc = 0; _vel_last_us = micros();
    out.println(F("mot.zero"));
    return true;
}
static bool doBrake(UniProto&, const char*, const char*, Stream& out, void*) {
    digitalWrite(PIN_BRAKE, HIGH);
    out.println(F("mot.brake"));
    return true;
}
static bool doCoast(UniProto&, const char*, const char*, Stream& out, void*) {
    digitalWrite(PIN_BRAKE, LOW);
    out.println(F("mot.coast"));
    return true;
}

// ── Setup / loop ──────────────────────────────────────────────────────────────
void setup() {
    // Motor shield pins
    pinMode(PIN_DIR,   OUTPUT); digitalWrite(PIN_DIR, LOW);
    pinMode(PIN_BRAKE, OUTPUT); digitalWrite(PIN_BRAKE, LOW);  // coast
    setupPWM();

    // Pot reference pins
    pinMode(PIN_POT_GND, OUTPUT); digitalWrite(PIN_POT_GND, LOW);
    pinMode(PIN_POT_VCC, OUTPUT); digitalWrite(PIN_POT_VCC, HIGH);
    pinMode(PIN_POT_SIG, INPUT);

    // Encoder
    pinMode(PIN_ENC_A, INPUT_PULLUP);
    pinMode(PIN_ENC_B, INPUT_PULLUP);
    attachInterrupt(digitalPinToInterrupt(PIN_ENC_A), encISR_A, CHANGE);
    attachInterrupt(digitalPinToInterrupt(PIN_ENC_B), encISR_B, CHANGE);

    _prev_us      = micros();
    _ctrl_next    = _prev_us;
    _vel_last_us  = _prev_us;
    _vel_last_enc = 0;

    Serial.begin(115200);
    proto.begin();
    proto.setRateHz(50);

    proto.registerStream({1,"mot","i32,f32,i32,f32,f32,f32","pos,set,cmd,err,vel,mA",emitMot,nullptr});

    proto.registerParam({"mot.enable",    UniProto::ParamType::BOOL,  getParam,setParam,nullptr});
    proto.registerParam({"mot.mode",      UniProto::ParamType::INT32, getParam,setParam,nullptr});
    proto.registerParam({"mot.kp",        UniProto::ParamType::FLOAT, getParam,setParam,nullptr});
    proto.registerParam({"mot.ki",        UniProto::ParamType::FLOAT, getParam,setParam,nullptr});
    proto.registerParam({"mot.kd",        UniProto::ParamType::FLOAT, getParam,setParam,nullptr});
    proto.registerParam({"mot.pwm_lim",   UniProto::ParamType::INT32, getParam,setParam,nullptr});
    proto.registerParam({"mot.set",       UniProto::ParamType::FLOAT, getParam,setParam,nullptr});
    proto.registerParam({"mot.pot_scale", UniProto::ParamType::FLOAT, getParam,setParam,nullptr});
    proto.registerParam({"mot.vel_scale", UniProto::ParamType::FLOAT, getParam,setParam,nullptr});
    proto.registerParam({"mot.ctrl_hz",   UniProto::ParamType::INT32, getParam,setParam,nullptr});
    proto.registerParam({"mot.vel_alpha", UniProto::ParamType::FLOAT, getParam,setParam,nullptr});
    proto.registerParam({"mot.pos",       UniProto::ParamType::INT32, getParam,setParam,nullptr});
    proto.registerParam({"mot.vel",       UniProto::ParamType::FLOAT, getParam,setParam,nullptr});
    proto.registerParam({"mot.mA",        UniProto::ParamType::FLOAT, getParam,setParam,nullptr});

    proto.registerAction({"mot.zero",  doZero,  nullptr});
    proto.registerAction({"mot.brake", doBrake, nullptr});
    proto.registerAction({"mot.coast", doCoast, nullptr});
}

static uint32_t _pot_next  = 0;

void loop() {
    uint32_t now = micros();

    // Control loop gated by _ctrl_hz
    if (now >= _ctrl_next) {
        _ctrl_next = now + (uint32_t)(1000000UL / _ctrl_hz);
        updateControl();
    }

    // Poll pot at 20Hz
    uint32_t now_ms = millis();
    if (now_ms >= _pot_next) {
        _pot_next = now_ms + 50;
        pollPot();
    }

    proto.tick();
}

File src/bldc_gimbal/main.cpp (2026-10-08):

#include <Arduino.h>
#include <Wire.h>
#include "UniProto.h"

// ── Device ────────────────────────────────────────────────────────────────────
// BLDC gimbal motor — minimal FOC, no SimpleFOC library.
// DRV8313 driver (3-PWM) + AS5600 absolute magnetic encoder (I2C).
// 
// The DRV8313 needs 12V, the AS5600 needs 3.3V.
//
// Wiring:
//   DRV8313 IN1 → pin 9    (phase A, Timer1 OC1A)
//   DRV8313 IN2 → pin 10   (phase B, Timer1 OC1B)
//   DRV8313 IN3 → pin 11   (phase C, Timer2 OC2A)
//   DRV8313 EN  → pin 8
//   AS5600 SDA  → A4,  SCL → A5
//
// Zero position:
//   The AS5600 reading at power-on is captured as _start_offset.
//   _angle always starts at 0.0 regardless of physical rotor position.
//   @foc.zero resets _angle=0 and _set=0 at the current position.
//
// FOC convention:
//   Electrical angle = _angle * poles (positive, no negation).
//   Spring: vq = +k * err  (positive vq = positive torque = increasing angle).
//   If spring pulls wrong way → swap any two motor phase wires.
//
// Control modes (!foc.mode):
//   0 = open loop  (direct Vq via !foc.vq, fixed electrical angle via !foc.theta)
//   1 = spring     (Vq = +k × error, pulls toward _set)
//   2 = detents    (Vq from detent potential wells)
//   3 = damper     (Vq = -b × velocity, opposes motion)
//   4 = spring + damper
//   5 = sweep      (electrical angle advances at _sweep_hz rev/sec)
// ─────────────────────────────────────────────────────────────────────────────

#define PIN_A    9
#define PIN_B    10
#define PIN_C    11
#define PIN_EN   8

#define AS5600_ADDR  0x36
#define AS5600_REG   0x0C   // ANGLE register (filtered, 12-bit, 0..4095)

// ── PWM ──────────────────────────────────────────────────────────────────────
static void setupPWM() {
    // Timer1: pins 9,10 — Fast PWM, TOP=255 → 62.5kHz
    // Using TOP=255 (same as Timer2) so all 3 phases have identical range.
    TCCR1A = (1<<COM1A1)|(1<<COM1B1)|(1<<WGM11);
    TCCR1B = (1<<WGM13)|(1<<WGM12)|(1<<CS10);
    ICR1 = 255; OCR1A = 127; OCR1B = 127;
    pinMode(PIN_A, OUTPUT); pinMode(PIN_B, OUTPUT);
    // Timer2: pin 11 — Fast PWM, prescale=1 → 62.5kHz
    TCCR2A = (1<<COM2A1)|(1<<WGM21)|(1<<WGM20);
    TCCR2B = (1<<CS20);
    OCR2A = 127;
    pinMode(PIN_C, OUTPUT);
}

static void motorOff() { OCR1A = 127; OCR1B = 127; OCR2A = 127; }

// ── AS5600 ───────────────────────────────────────────────────────────────────
static uint16_t _raw_count = 0;

// Returns raw sensor angle 0..2π. No offset subtraction — keep it simple.
// Zero reference is handled by initialising _prev = first reading,
// so _angle starts at 0 naturally. @foc.zero resets _angle and _set.
static float readAS5600() {
    Wire.beginTransmission(AS5600_ADDR);
    Wire.write(AS5600_REG);
    if (Wire.endTransmission(false) != 0) return -1.0f;
    Wire.requestFrom((uint8_t)AS5600_ADDR, (uint8_t)2);
    if (Wire.available() < 2) return -1.0f;
    uint16_t raw = ((uint16_t)(Wire.read() & 0x0F) << 8) | Wire.read();
    _raw_count = raw;
    return raw / 4095.0f * 2.0f * (float)PI;   // 0..2π, absolute
}

// ── params ───────────────────────────────────────────────────────────────────
static bool  _enabled  = false;
static int   _poles    = 7;
static float _vsupply  = 12.0f;
static float _vlimit   = 2.0f;
static int   _mode     = 1;
static float _set      = 0.0f;
static float _k        = 2.0f;
static float _b        = 0.3f;
static float _detent   = 0.5236f;   // 30° in rad
static float _detent_k = 8.0f;
static float _vq_cmd   = 2.0f;
static float _th_open  = 0.0f;
static float _sweep_hz = 0.5f;
static float _ph_off   = 0.0f;   // electrical phase offset (rad) — tune for sweep symmetry

// ── state ────────────────────────────────────────────────────────────────────
static float    _angle   = 0.0f;   // unwrapped angle from startup zero (rad)
static float    _vel     = 0.0f;   // filtered angular velocity (rad/s)
static float    _vq      = 0.0f;
static float    _prev    = 0.0f;   // previous readAS5600() for unwrap
static uint32_t _last_us = 0;

// ── FOC output ───────────────────────────────────────────────────────────────
static void setPhases(float vq, float theta) {
    const float TP = 2.0f * (float)PI;
    theta = theta - TP * floorf(theta / TP);

    float va = vq * sinf(theta);
    float vb = vq * sinf(theta + 2.09440f);
    float vc = vq * sinf(theta + 4.18879f);

    float n = (_vsupply > 0.1f) ? _vsupply : 12.0f;

    auto clamp01 = [](float x) -> float {
        return x < 0.0f ? 0.0f : (x > 1.0f ? 1.0f : x);
    };
    // All three phases now use identical 0-255 range — fully symmetric
    uint8_t pa = (uint8_t)(clamp01(va / n + 0.5f) * 255.0f);
    uint8_t pb = (uint8_t)(clamp01(vb / n + 0.5f) * 255.0f);
    uint8_t pc = (uint8_t)(clamp01(vc / n + 0.5f) * 255.0f);
    OCR1A = pa;
    OCR1B = pb;
    OCR2A = pc;
}

// ── control ──────────────────────────────────────────────────────────────────
static float computeVq() {
    // Unwrapped error: positive when rotor is ahead of setpoint.
    // Spring pulls back to _set across any number of full turns.
    float err = _angle - _set;

    switch (_mode) {
        case 0: return _vq_cmd;

        case 1:
            return -_k * err;

        case 2: {
            // fmodf preserves the sign of the dividend, so detents only
            // work correctly on the positive side of zero (err > 0).
            // On the negative side the sawtooth phase is offset and does
            // not oscillate symmetrically. This is by design — detents
            // start from zero and extend in one direction only.
            // To get symmetric detents in both directions, replace fmodf
            // with a positive modulo:
            //   float e = err - _detent * floorf(err / _detent);
            //   float phase = e - half;
            float half  = _detent * 0.5f;
            float phase = fmodf(err + half, _detent) - half;
            return -_detent_k * phase;
        }

        case 3:
            return -_b * _vel;

        case 4:
            return -_k * err - _b * _vel;

        case 5:
            return _vq_cmd;

        default: return 0.0f;
    }
}

// ── UniProto ─────────────────────────────────────────────────────────────────
UniProto proto(Serial, "BLDCGimbal");

static void emitFoc(UniProto&, uint8_t sid, UniFrameWriter& w, void*) {
    w.begin(sid);
    w.f32(_angle,     "pos", 3);
    w.f32(_vel,       "vel", 3);
    w.f32(_set,       "set", 3);
    w.f32(_vq,        "vq",  2);
    w.u16(_raw_count, "cnt");
    w.end();
}
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

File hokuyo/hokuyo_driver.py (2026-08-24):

"""
hokuyo_driver.py

Minimal SCIP2.0 driver for the Hokuyo URG-04LX-UG01, talking to the sensor
over its USB virtual serial port (shows up as /dev/tty.usbmodemXXXX on macOS).

Reference: Hokuyo SCIP 2.0 communication protocol. Distance values are
encoded as 3 printable ASCII characters per point, 6 bits each, offset
by 0x30, most-significant character first. The scanner exposes 1024 steps
per revolution (360 / 1024 deg/step); step 384 points straight ahead, and
the sensor's usable 240 degree field of view spans steps 44 to 725.

This has been written against the protocol spec but not yet run against
physical hardware -- before trusting distances, point the sensor at a
wall you've measured by hand and confirm get_scan() agrees.
"""
from __future__ import annotations

import time
from dataclasses import dataclass
from typing import Iterator, List, Tuple

import serial

SCIP_ENCODE_OFFSET = 0x30
BITS_PER_CHAR = 6

START_STEP = 44
END_STEP = 725
FRONT_STEP = 384
STEPS_PER_REV = 1024
STEP_ANGLE_DEG = 360.0 / STEPS_PER_REV


class HokuyoError(RuntimeError):
    """Raised when the sensor replies with a non-success status code."""


@dataclass
class Scan:
    timestamp: float
    angles_deg: List[float]
    distances_mm: List[int]


def _decode(chars: str) -> int:
    value = 0
    for ch in chars:
        value = (value << BITS_PER_CHAR) | (ord(ch) - SCIP_ENCODE_OFFSET)
    return value


class HokuyoURG:
    def __init__(self, port: str, baudrate: int = 115200, timeout: float = 1.0):
        self._ser = serial.Serial(port, baudrate=baudrate, timeout=timeout)
        # Older firmware boots in SCIP1.1; this switches to SCIP2.0 and is a
        # harmless no-op if the sensor is already in that mode.
        self._command("SCIP2.0", expect_status=False)
        self._command("BM")  # laser on

    def close(self) -> None:
        try:
            self._command("QT", expect_status=False)
        except Exception:
            pass
        self._ser.close()

    def __enter__(self) -> "HokuyoURG":
        return self

    def __exit__(self, *exc) -> None:
        self.close()

    # -- low level -----------------------------------------------------

    def _send_line(self, text: str) -> None:
        self._ser.write((text + "\n").encode("ascii"))

    def _read_line(self) -> str:
        raw = self._ser.readline()
        return raw.decode("ascii", errors="replace").rstrip("\n")

    def _read_block(self) -> List[str]:
        """Read lines until the blank line that terminates a reply."""
        lines = []
        while True:
            line = self._read_line()
            if line == "":
                break
            lines.append(line)
        return lines

    def _command(self, cmd: str, expect_status: bool = True) -> List[str]:
        self._send_line(cmd)
        lines = self._read_block()
        if not lines or lines[0] != cmd:
            raise HokuyoError(f"Echo mismatch for {cmd!r}: got {lines!r}")
        if expect_status:
            if len(lines) < 2 or not lines[1].startswith("00"):
                status = lines[1] if len(lines) > 1 else "<none>"
                raise HokuyoError(f"Sensor rejected {cmd!r}: status {status!r}")
        return lines

    @staticmethod
    def _points_from_payload(payload: str, cluster_count: int) -> Tuple[List[float], List[int]]:
        step_span = max(cluster_count, 1)
        angles, distances = [], []
        step = START_STEP
        # payload is 3-char-encoded distances back to back; trailing partial
        # groups (padding) are ignored.
        for i in range(0, len(payload) - 2, 3):
            distances.append(_decode(payload[i:i + 3]))
            angles.append((step - FRONT_STEP) * STEP_ANGLE_DEG)
            step += step_span
        return angles, distances

    # -- public API ------------------------------------------------------

    def get_scan(self, cluster_count: int = 0) -> Scan:
        """Request a single full-range scan (blocking)."""
        cmd = f"GD{START_STEP:04d}{END_STEP:04d}{cluster_count:02d}"
        lines = self._command(cmd)
        # lines[0]=echo, lines[1]=status, lines[2]=timestamp, rest=data
        data_lines = lines[3:]
        payload = "".join(line[:-1] for line in data_lines)  # drop per-line checksum char
        angles, distances = self._points_from_payload(payload, cluster_count)
        return Scan(timestamp=time.time(), angles_deg=angles, distances_mm=distances)

    def iter_scans(
        self,
        cluster_count: int = 0,
        scan_interval: int = 0,
        num_scans: int = 0,
    ) -> Iterator[Scan]:
        """Continuously stream scans via MD. num_scans=0 means unlimited."""
        cmd = f"MD{START_STEP:04d}{END_STEP:04d}{cluster_count:02d}{scan_interval:01d}{num_scans:02d}"
        self._send_line(cmd)
        lines = self._read_block()
        if not lines or lines[0] != cmd or not lines[1].startswith("00"):
            raise HokuyoError(f"Sensor rejected {cmd!r}: {lines!r}")

        count = 0
        while num_scans == 0 or count < num_scans:
            lines = self._read_block()
            if len(lines) < 4:
                continue  # transient hiccup; keep listening
            data_lines = lines[3:]
            payload = "".join(line[:-1] for line in data_lines)
            angles, distances = self._points_from_payload(payload, cluster_count)
            yield Scan(timestamp=time.time(), angles_deg=angles, distances_mm=distances)
            count += 1

    def stop_scanning(self) -> None:
        """Interrupt a running iter_scans() stream from another thread's view
        by sending QT; the generator's next read will then fail/stop."""
        self._send_line("QT")

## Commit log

2025-12-30 added module code for PSD sensor
2025-12-30 added bldc module (not finished)
2025-12-31 bldc edit (not working yet)
2026-06-08 updated project, 3 units confirmed
    [synchro.scad, synchro.stl]
2026-07-28 working wind sensor and sensorshield full sketch
2026-08-24 working python visualisers for kinect and hokuyo lidar
2026-08-28 dc motor and dual motor separated
2026-10-01 switched adns to default continuous mode
2026-10-29 added sensorshield json
